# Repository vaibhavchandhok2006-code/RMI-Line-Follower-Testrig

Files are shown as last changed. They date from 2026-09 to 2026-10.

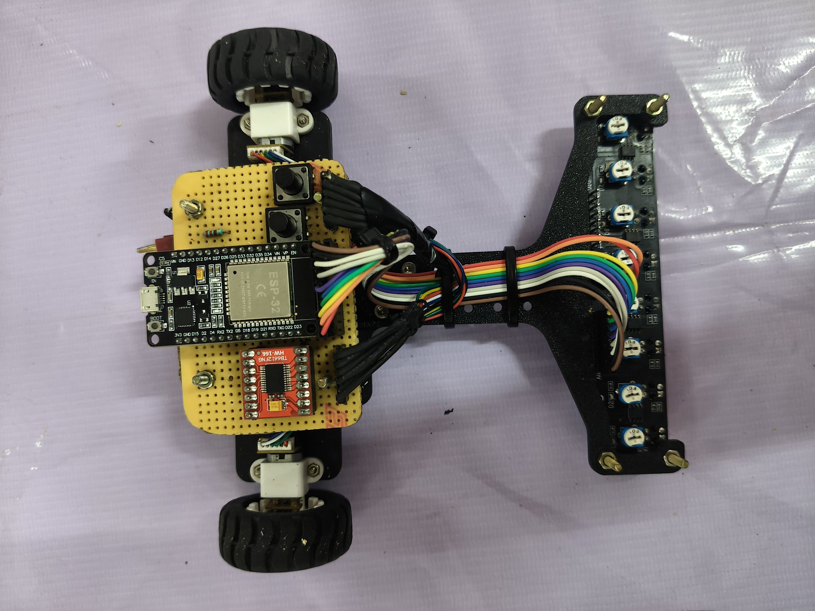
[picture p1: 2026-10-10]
media/photos/05_front_view_sensor_array.jpg

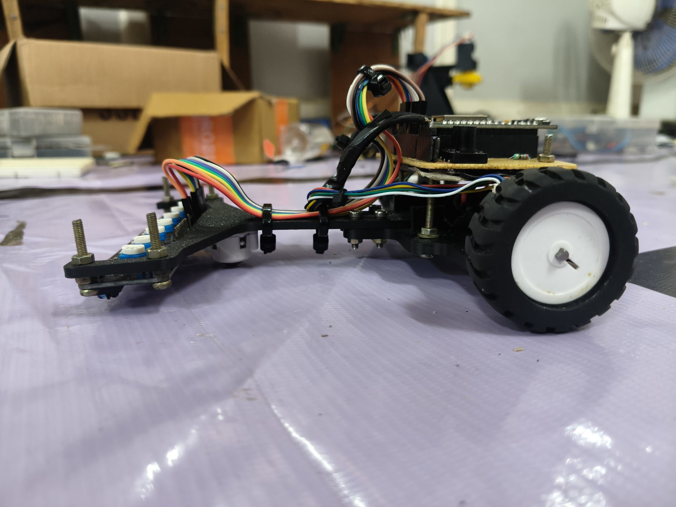
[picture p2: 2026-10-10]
media/photos/04_underside_sensor_array.jpg

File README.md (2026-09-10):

# Line Follower — RMI TestRig Project

## Overview
Differential-drive line-following robot built as a part of RMI Testrig. Follows a 38mm black line through a hostile track (sharp corners, junctions), runs an exploration round to build a track map, then executes an optimized second run using path-planning on the discovered graph.

Design review stage — CAD assembly and circuit design complete, firmware development starting next.

## Repo Structure
- `/cad` — SolidWorks assembly + exported STL files, chassis, motor mounts, sensor mount
- `/docs` — circuit diagram, BOM
- `/firmware` — ESP-IDF firmware (in progress)
- `BUILDLOG - Mentions the project journey
- `README` - Mentions repo structure , project description, required summaries

## Hardware Summary
- ESP32 (compute + control)
- 2× N20 motors with encoders (drive + odometry)
- RLS-08 IR reflectance sensor array (line sensing)
- TB6612FNG motor driver
- 2S LiPo battery, 7.4V nominal, LM2596 buck converter for 5V rail
- Full BOM: see `/docs/bom.md`

## How to Build / Run
Firmware setup instructions will be added once ESP-IDF development begins. CAD files can be opened directly in SolidWorks or viewed via the exported STL file.

## Team
Vaibhav Chandhok, 2nd year Mechanical, RMI Robotics and Machine Intelligence Club , NIT Trichy

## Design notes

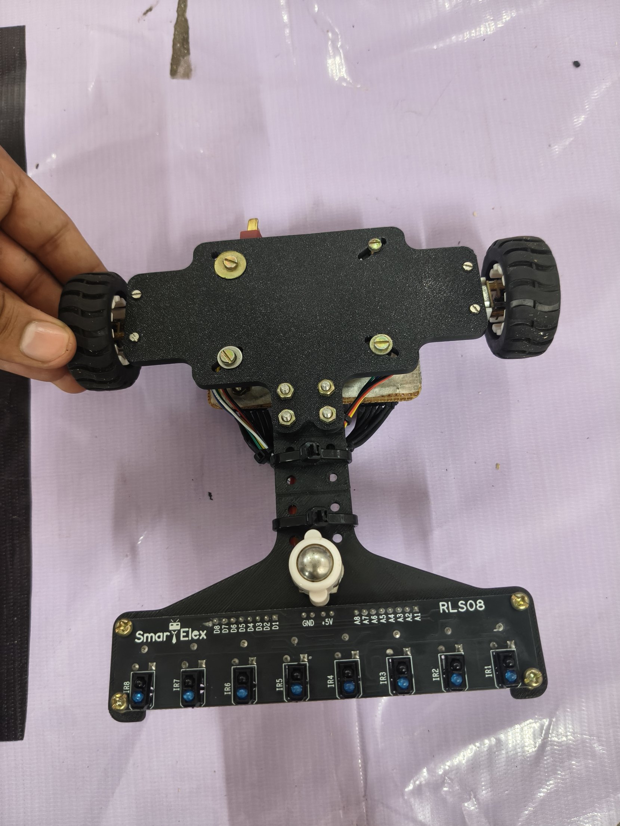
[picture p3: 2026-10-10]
media/photos/06_side_view.jpg

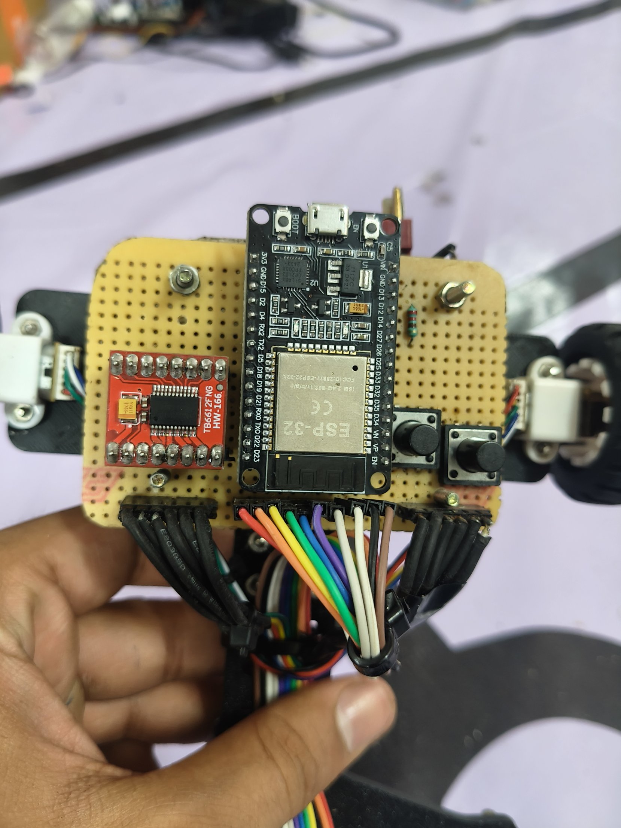
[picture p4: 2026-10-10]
media/photos/03_controller_board_closeup.jpg

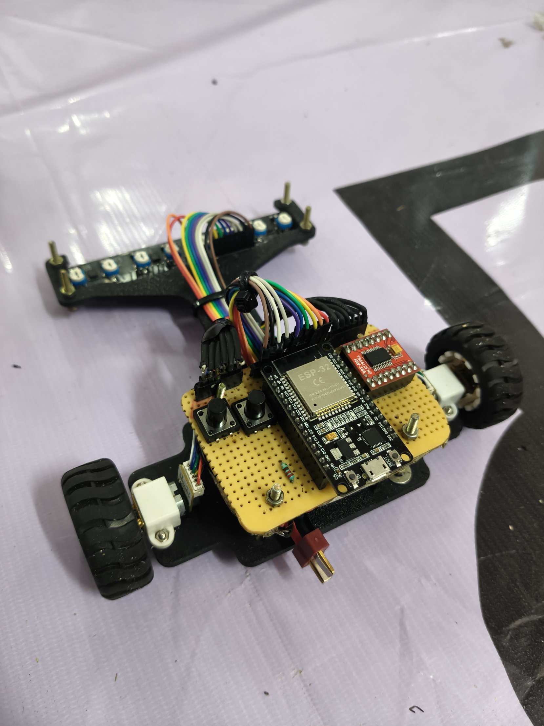
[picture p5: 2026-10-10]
media/photos/01_top_view.jpg

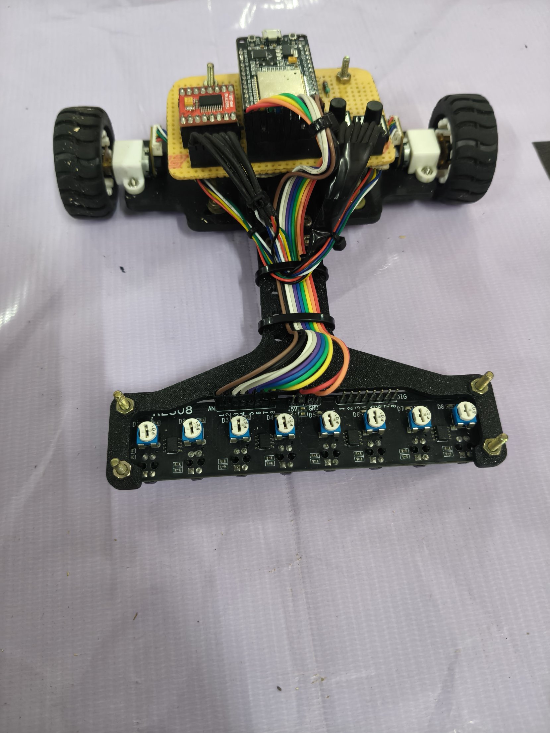
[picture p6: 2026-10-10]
media/photos/02_angled_view.jpg

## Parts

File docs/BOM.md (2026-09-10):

# Bill of Materials

## Electronics — Compute, Sensing, Actuation

| S No. | Component | Quantity | Available in Inventory? |
|---|---|---|---|
| 1 | ESP32 | 1 | Yes |
| 2 | N20 motors with encoders | 2 | Yes |
| 3 | N20 wheels | 2 | Yes |
| — | Caster wheel (compatible with N20 motor height) | 1 | Yes |
| 4 | N20 motor mounts | 2 | Yes |
| 5 | RLS-08 (8-channel IR reflectance sensor array) | 1 | Yes |
| 6 | Motor driver (TB6612FNG) | 1 | Added from personal stock |
| 7 | Battery — LiPo, 7.4V, 850mAh | 1 | Yes |
| 8 | Buck Converter (LM2596, 5V rail) | 1 | Yes |

## Electrical — Wiring, Power, Protection

| S No. | Component | Quantity | Available in Inventory? |
|---|---|---|---|
| 9 | Perfboard, 90×60mm | 1 | Added from personal stock |
| 10 | Male/female header pins | ~20-30 | Yes |
| 11 | JST or XT connector (battery) | 1 | Yes |
| 12 | Jumper wires | ~15-20 | Yes |
| 13 | Voltage divider resistors | Small quantity | Yes |
| 14 | Status LEDs | 2-3 | Yes |
| 15 | Capacitors (voltage smoothing) | As required | Yes |
| 16 | Switches — power on/off, calibration trigger, run trigger | 3 total | Yes |

## Mechanical — Fasteners, Inserts, Structure

| S No. | Component | Quantity | Available in Inventory? |
|---|---|---|---|
| 17 | PLA filament | As needed | Yes |
| 18 | Brass heat-set inserts (PCB mount, motor mount — matched to available bolts in SAC) | 8-10 | Yes |
| 19 | M3 bolts | 10-12 | Yes |
| 20 | Printed or metal standoffs | 4 | Yes |
| 21 | Zip ties, heat-shrink tubing, solder, and other basic build tools | As needed | Yes |

---

**Items sourced outside RMI inventory:** TB6612FNG motor driver and the 90×60mm perfboard were added from personal stock — flagged explicitly per the review's requirement to call out anything not from club inventory.

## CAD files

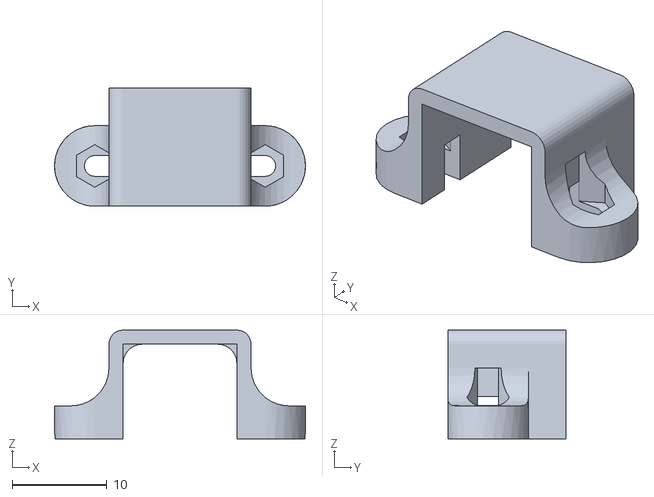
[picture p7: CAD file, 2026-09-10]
cad/parts/N20 motor mount.stl
26.5 x 12.5 x 11.5

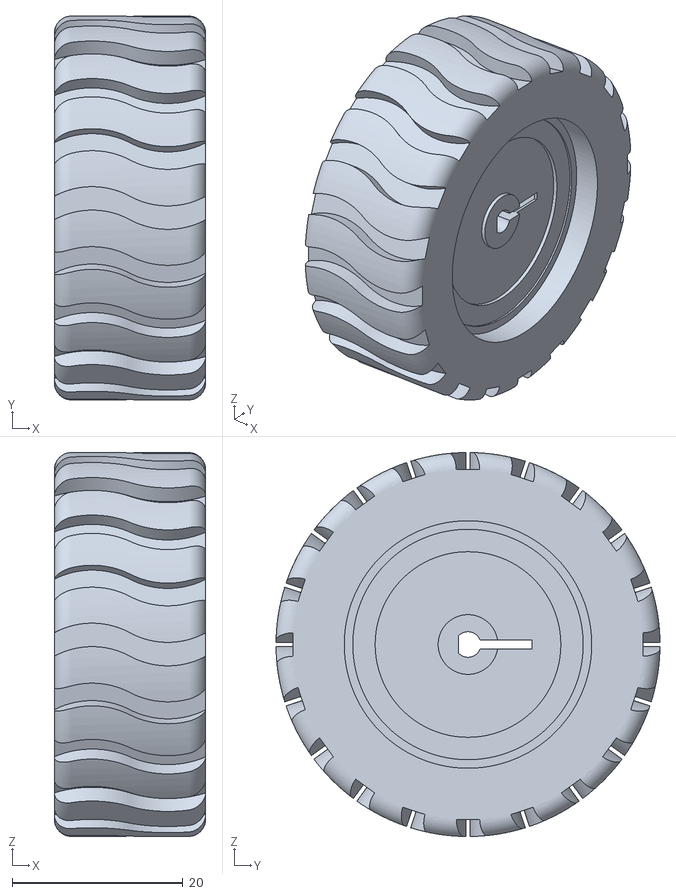
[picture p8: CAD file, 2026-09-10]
cad/parts/N20 Wheel D43 mm.stl
17.8 x 45.0 x 45.0

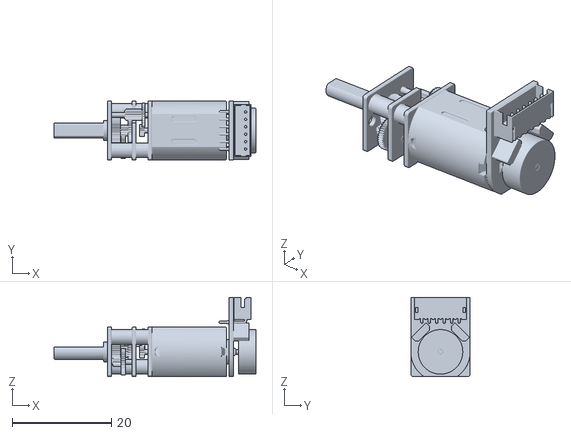
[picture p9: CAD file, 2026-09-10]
cad/parts/n20 motor stl.stl
40.8 x 12.0 x 16.0

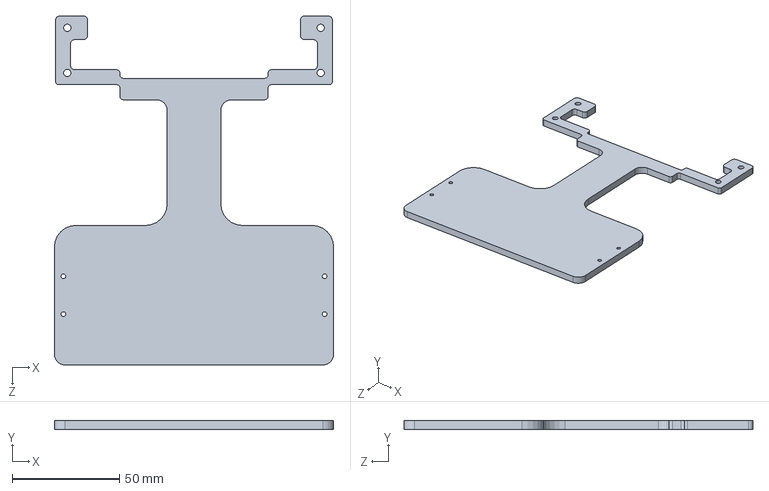
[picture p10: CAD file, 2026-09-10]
cad/parts/Line follower Chasis.SLDPRT
130.0 x 4.00 x 162.5 mm

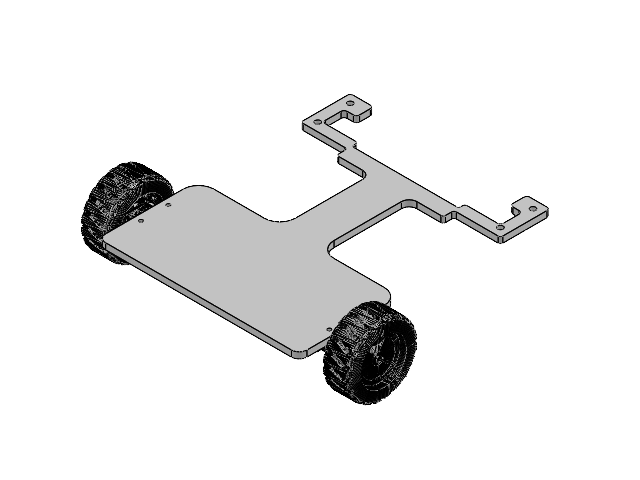
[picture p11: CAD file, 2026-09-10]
cad/parts/Assembly file.SLDASM
Line follower
m20 motor mount sld x 2
n20 motor sldmain x 2
N20 Wheel D43 mm sld x 2

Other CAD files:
cad/parts/n20 motor sldmain.SLDPRT
cad/parts/N20 Wheel D43 mm sld.SLDPRT
cad/parts/m20 motor mount sld.SLDPRT

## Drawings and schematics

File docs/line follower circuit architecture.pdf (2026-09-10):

# Line follower circuit architecture

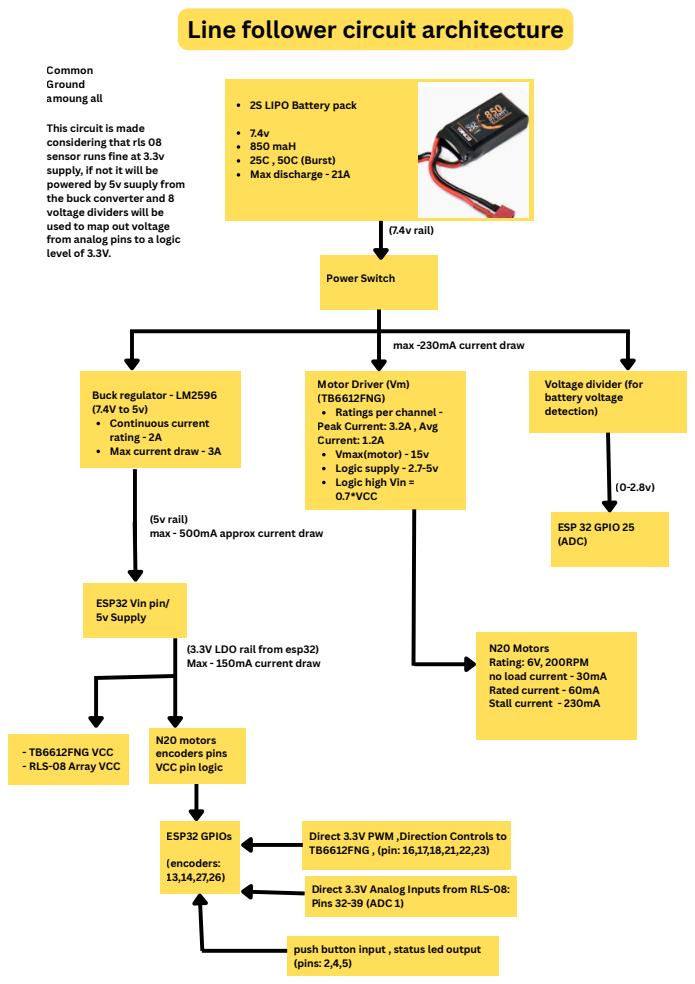
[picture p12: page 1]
7.4v 850 maH 25C , 50C (Burst) Max discharge - 21A; ESP 32 GPIO 25 (ADC); (0-2.8v) ESP32 Vin pin/; 5v Supply; (7.4v rail) Common Ground amoung all; ESP32 GPIOs; (encoders: 13,14,27,26)

2S LIPO Battery pack

This circuit is made
considering that rls 08
sensor runs fine at 3.3v
supply, if not it will be
powered by 5v suuply from
the buck converter and 8
voltage dividers will be
used to map out voltage
from analog pins to a logic
level of 3.3V.

Power Switch Buck regulator - LM2596

max -230mA current draw

Motor Driver (Vm)
(TB6612FNG)
Ratings per channel -
Peak Current: 3.2A , Avg
Current: 1.2A
Vmax(motor) - 15v
Logic supply - 2.7-5v
Logic high Vin =
0.7*VCC

Voltage divider (for
battery voltage
detection)

Continuous current
rating - 2A
Max current draw - 3A

(5v rail)
max - 500mA approx current draw

(3.3V LDO rail from esp32)
Max - 150mA current draw

N20 Motors
Rating: 6V, 200RPM
no load current - 30mA
Rated current - 60mA
Stall current - 230mA

N20 motors
encoders pins
VCC pin logic

- TB6612FNG VCC
- RLS-08 Array VCC

Direct 3.3V PWM ,Direction Controls to
TB6612FNG , (pin: 16,17,18,21,22,23)

Direct 3.3V Analog Inputs from RLS-08:
Pins 32-39 (ADC 1)

push button input , status led output
(pins: 2,4,5)

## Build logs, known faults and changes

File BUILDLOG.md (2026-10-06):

# Build Log

Progressive log of design decisions, what was tried, what changed, and why. 
---

### Aug 7 — Project start
- Allotted the Line Follower project, built a personal roadmap , timeline.
- Started learning Github.
- Set up this GitHub repo.

### Aug ~10-13 — Kinematics
- Learnt about differential  drive kinematics.
- Worked through how sensor mounting offset from the wheel axis affects control

### Aug 13 — Chassis and sensor design constraints research 
- Did a literature survey , used AI tools find the most relevant research papers , links , videos for the project knowledge
- Drafted design requirements sheet: 38mm line, sensor array width, 5-8 sensors, 10-19mm spacing, 5-8mm mount height, front-mounted array ahead of wheel axle.
- Made a rough component list
- Through the learnings from the literature survey defined design requirements 

### Aug 13-15 — Sensor hardware verification
- Checked actual RLS-05/RLS-08 datasheets against assumed design numbers. Found the initially planned mounting height (8-12mm) was too high for the real sensors' recommended sensing distance (RLS-08: ~6mm, RLS-05: ~3mm optimal). Corrected target to 5-6mm with adjustable mount.
- Computed array width and critical entry angle for available options:
  - RLS-08 full 8ch: 105mm width 
- Decision: proceeded with full RLS-08 (8ch) after confirming inventory availability — to be validated against actual measured track .

### Aug 15-20 — Circuit architecture, CAD Design and component finalization
- Finalized BOM: confirmed availability of ESP32, N20 motors w/ encoders, caster wheel, motor mounts, RLS-08, TB6612FNG,Battery , Buck converter and mechanical hardware in RMI inventory.
- Designed power architecture: 2S LiPo (7.4V nominal) → power switch → splits to (a) TB6612FNG VM pin directly, (b) LM2596 buck converter → 5V rail → ESP32 VIN + N20 encoder VCC + level shifter HV side.
- Caught a real issue: N20 encoder outputs run at 5V logic, which would be unsafe wired directly into ESP32's 3.3V-only GPIOs. Added a 4-channel logic level shifter to bring encoder signals down to 3.3V.
- Assigned all 8 RLS-08 analog channels to ESP32 ADC1 pins (GPIO32-39) specifically because ADC2 becomes unreliable once Wi-Fi is active — needed for the telemetry stretch objective.
- Routed battery voltage divider to GPIO25 (ADC2) as a deliberate exception, since battery monitoring doesn't need real-time precision the way line sensing does.
- Sized battery voltage divider (10kΩ / 5.6kΩ) so that worst-case 8.4V (full charge) maps to ~3.02V at the ESP32 ADC pin, safely under the 3.3V limit.
- Computed peak current budget (~3A instantaneous: 2× motor stall + Wi-Fi-active ESP32 + sensor array) to size the battery/driver requirements.
- Built the first draft of the Chasis

### Aug 20 -22 — CAD assembly
- Donwloaded the n20 motor , mounts , wheel cad models from grabcad
- Built first-pass chassis assembly in SolidWorks: N20 motors, motor mounts, wheels assembled onto chassis baseplate.

### Aug 23 — Design review

### Aug 26 — Circuit reiteration: component spec audit

Design review on the 23rd landed mid-CT, so a lot of it was deadline-chasing rather than actually thinking things through. Today's the real reiteration pass — went back to first-party specs for every major component instead of the assumed numbers from before.

- **RLS-08 IR array**: 100–150mA draw, rated 5V, gives 0–5V analog out (per Robu.in). Also runs at 3.3V, but only if the LED current-limiting resistor stage (two-stage arrangement on-board) is shorted/bypassed — needs on-board soldering rework.(to be confirmed)
  - If the bypass works: 3.3V is sufficient, no voltage divider needed on the 8 analog lines.
  - If not: fall back to 5V off the buck converter + 8× voltage dividers to bring the ADC lines to 3.3V logic.
  - Not decided yet — will try the 3.3V supply.
- **N20 motor**: 6V rated, 200RPM. No-load current 30mA, rated 60mA, stall 230mA.
- **N20 encoder**: red/blue = GND + motor power, black = encoder VCC (3.3–5V logic), yellow/green = signal feedback (logic-high tracks whatever VCC is supplied). Going with 3.3V logic to match ESP32 GPIOs directly.
- **TB6612FNG driver**: 1.2A continuous / 3.2A peak per channel, Vmotor max 15V, logic supply 2.7–5.5V. Logic-high threshold is 0.7×VCC — this is the actual reason 3.3V logic was chosen over 5V: at 3.3V VCC the threshold sits low enough for ESP32's native 3.3V GPIO high to drive it cleanly. At 5V VCC, the threshold would sit above what a 3.3V GPIO can output.
- **Battery**: 7.4V 2S LiPo, 850mAh, 25C continuous / 50C burst, ~21A max discharge.
- **ESP32**: onboard LDO accepts 5–12V in, fed from the buck-converted 5V rail → 3.3V LDO out. Max output 250mA , per GPIO - 20mA recommended, Wi-Fi/BT TX peak current 240–500mA — factored into the current budget.
- **Buck converter (LM2596)**: 2A continuous, 3A max — heatsink required above ~2A.

**Open question:** whether to feed the raw 7.4V LiPo rail straight into ESP32 Vin. Technically within the 5–12V input range but still need to confirm , some online source suggested that ideally 5-7V should be fed into esp32 LDO.

Updated circuit architecture diagram reflects all of the above: 7.4V rail → power switch → splits three ways (buck → 5V rail, direct to motor driver Vm, divider → battery-voltage ADC). Pin assignments locked: encoders on GPIO13/14/27/26, motor driver PWM+direction on 16/17/18/21/22/23, RLS-08 analog on GPIO32-39 (ADC1), push button + status LED on 2/4/5.

Next: once the RLS-08 power path is settled , will move to CAD assemble re - ideation .

### Aug 27–29 — Chassis v2: split design, adjustable sensor arm

(Didn't log day-by-day through this stretch — heads-down on CAD. Catching up in one entry covering the full 3-day iteration.)

The previous chassis was rushed to hit the design review deadline and wasn't actually good. This is the real redesign.

**Split into two parts** instead of one solid baseplate:
1. **Back chassis plate** — motor mounts + PCB area + battery mount
2. **Adjustable IR sensor arm** — separate piece, bolts on

**Back chassis plate**
- Previous version was one full rectangular block, which carried dead weight on either side of the motors for no reason. New version thins those sections down to just what the motor mounts need, cutting that mass out.
- PCB footprint minimized to 80mm × 60mm to keep mass down; PCB sits on standoffs ~1.5–2cm above the plate.
- 4mm thick, printed at 60% infill.
- The PCB Mounting fall are made as slots rather than fixed holes if a smaller PCB is possible to make it can mounted and hence the mounting holes are adjustable.

**Adjustable IR sensor arm:**
- Look-ahead distance adjustable from 8cm to 20cm, with 1cm-spaced grooves as cut guides. Once track calibration shows the ideal look-ahead distance, the arm gets trimmed to length and bolted to the chassis plate through two front mounting holes.
- Originally planned to mount this *below* the back plate, but that removed the ground clearance for the sensor head and removed any adjustability — moved it above instead.
- 3mm thick (kept minimal since it's not load-bearing), printed at 70–80% infill to compensate for the reduced thickness.
- Caster wheel sits directly below the arm's front section, with a 2mm gap between the arm's underside and the caster when mounted. No threaded mount for the caster — will be secured with double-sided tape instead of screws.

**Test prints completed:** caster wheel mounting hole, bolt diameter tolerances, IR sensor array mount. Final full-chassis prints still pending.

**Custom CAD parts modeled from scratch** (no usable models existed online): LiPo battery, caster wheel, IR sensor array — built to complete the full assembly for fit-checking.

**Full assembly**


**Chasis Main Back Plate**



**Adjustable IR Sensor array part with Castor wheel and cutting grooves**


**Chassis assembly complete, all parts 3D printed**
- All chassis parts printed in PLA 3D Printer and assembled: baseplate, N20 motor mounts, wheels, caster mount.
- Final assembly photo:
IMG_20260829_163451 jpg

- Mechanical build phase complete. Moving into electronics wiring and ESP-IDF firmware development next.

### Sep 1 — ESP-IDF setup, first GPIO program
- ESP-IDF installed and toolchain working (separate learning curve from Arduino IDE — different build system, no hand-holding on peripheral config).
- Wrote first "Hello World" program to confirm the flash/build/monitor workflow.
- Wrote first LED blink program using raw GPIO driver calls (gpio_reset_pin, gpio_set_level, vTaskDelay) instead of Arduino's digitalWrite/delay abstractions.
- Decision: spending few days on ESP-IDF fundamentals before touching sensor/motor code, given how different the peripheral driver model is from Arduino. Following an online ESP-IDF tutorial series to build this foundation properly rather than rushing into the project code cold.
- Learned to configure and control multiple output pins .
- Learned digital input handling — reading a push button through ESP-IDF's GPIO input configuration (pull-up/pull-down config, gpio_get_level()).

### Sep 3-4 — PWM/LEDC control, first real ESP-IDF build issue
- Learned to control LED brightness via PWM using ESP-IDF's LEDC peripheral driver.
- Hit the first real build failure of the project: `fatal error: driver/ledc.h: No such file or directory`.

### Sep 9 — Sensor hardware setback, motor control confirmed working
- Discovered a hardware fault on the RLS-08: connecting 5V and GND caused the ESP32/Arduino power supply itself to browning out/switch off — strongly indicates a short on the sensor board, not a wiring or code issue on my end.
- As a temporary workaround, tested a spare 5-channel digital IR sensor module. Digital reads worked correctly in firmware, but the board itself is unusable for this project: its onboard threshold-setting potentiometer was never soldered at the factory, so there's no way to calibrate detection thresholds on it.
- Decision: waiting for the RLS-08 to be audited/replaced rather than building around the substitute digital board. The project spec explicitly requires a continuous weighted position estimate, which a digital (on/off per channel) sensor fundamentally cannot provide regardless of calibration — so this isn't a workaround worth forcing, it's the wrong sensor type for the requirement.
- Meanwhile, progressed on a parallel subsystem: single motor (Motor A) digital control via TB6612FNG fully working — forward/stop/reverse cycle confirmed on real hardware, STBY/AIN1/AIN2/PWMA wiring and control logic verified correct.
- Next: motor B, then PWM speed control layered on top of the working digital control, while sensor hardware issue is resolved in parallel.

## 10th September 2026 - Motor Control Hardware Drivers, PWM Integration & Firmware Repo Setup

### Summary
Successfully upgraded the dual DC motor driver firmware on ESP32 to support PWM speed control using ESP-IDF's LEDC peripheral. Structured the initialization routines into clean setup functions and integrated the local project folder into the main GitHub repository structure.

### Hardware & Pins Configured
* **Motor A (Left Drive):** `PWMA` (GPIO 16), `AIN1` (GPIO 17), `AIN2` (GPIO 18)
* **Motor B (Right Drive):** `PWMB` (GPIO 19), `BIN1` (GPIO 21), `BIN2` (GPIO 22)
* **Driver Control:** `STBY` (GPIO 23)

### Firmware Implementation Details
1. **GPIO & Direction Control:** Configured directional H-Bridge outputs (`AIN1/2`, `BIN1/2`) and driver enable (`STBY`).
2. **LEDC Hardware PWM Integration:** 
   * Configured `LEDC_TIMER_0` in `LEDC_LOW_SPEED_MODE` running at **5 kHz** to eliminate audible motor whine.
   * Configured **10-bit resolution** (duty cycle values from `0` to `1023`).
   * Linked `LEDC_CHANNEL_0` to Motor A (`PWMA`) and `LEDC_CHANNEL_1` to Motor B (`PWMB`).
3. **Control Routines:**
   * Modularized setup into `gpio_init()`, `pwm_init()`, and a master `motor_system_init()` sequence to prevent floating pin motor twitching on startup.
   * Created safe dynamic motor functions (`set_motor_a_speed`, `set_motor_b_speed`) with speed range clamping protection.

### Challenges & Resolutions
* **Git Remote Conflict (`non-fast-forward`):** Encountered push rejections due to diverged history between remote updates (`BUILDLOG.md`) and local files. Resolved using `git pull origin main --allow-unrelated-histories`.
* **File Structure Merge Conflict:** Conflict arose over `firmware/.gitignore` present in both local and remote branches. Aborted rebase, resolved conflicts, and staged manually using `git add .` and a merge commit.
* **Line Ending Conversion (CRLF/LF):** Handled cross-platform line ending normalization warnings during Git staging on Windows.
* **IntelliSense Include Path Warnings:** Identified red squiggly lines under `#include <driver/gpio.h>` as VS Code header resolution warnings caused by file directory restructuring; verified code compilation independently.

## not yet resolved
- RLS-08 power path: 3.3V direct (needs resistor-stage bypass mod) vs 5V + 8× voltage dividers — pending 3.3V feasibility test
- ESP32 Vin: raw 7.4V LiPo direct vs regulated 5V rail — undecided (raw only possible if the rls sensor runs at 3.3V)

### Sep 17 — Motor driver integration confirmed, borrowed RLS-08 for sensor code testing, baseline subtraction issue diagnosed

**Motor control — done, encoders not yet integrated**
- Motor driver (TB6612FNG) integration confirmed working on real hardware: forward, reverse, and stop all verified with both motors under LEDC PWM control.
- Encoders not wired in yet — motor motion currently open-loop, no speed/position feedback. Consistent with the roadmap: encoders are a deferred stretch item (odometry), not required for core.

**Sensor testing — using a borrowed RLS-08, own unit still not delivered**
- My own RLS-08 hasn't arrived yet. Borrowed another RMI member's RLS-08 unit specifically to test and develop the sensor-reading code against real hardware in the meantime, rather than staying blocked.
- Ran the 8-channel sensor test code (6ch on ADC1, 2ch on ADC2) against the borrowed array and logged real readings across a range of hand-swept positions over the line.

**Diagnosed: white-baseline subtraction issue**
- Logged data showed the line (black) consistently read higher than background (white), confirming correct polarity — no inversion needed in the weighted-position formula.
- However, all sensors carried a substantial baseline offset (~80-100 raw counts) even on plain white background. Since the weighted-average formula divides by the sum of all raw readings, this baseline was diluting the effective signal — reworking one logged example (strong left-side line detection) showed the computed position was roughly 3x weaker than physically expected once the baseline was accounted for by hand.
- Root cause: sensor readings were being used raw/uncalibrated, with no per-sensor min/max subtraction or normalization. This is exactly the calibration requirement the spec mandates, now confirmed empirically rather than just theoretically.
- Also observed: sensor-to-sensor baseline varies by 10-20 raw counts even on identical white background — consistent with expected manufacturing/mounting variation discussed earlier, reinforces need for *per-sensor* calibration rather than a single shared threshold.
- Observed contrast (white vs black) is currently small in absolute terms, and improves when sensor height is reduced. Decision: check for an onboard gain trimmer before lowering mount height further, since height reduction trades contrast for ground clearance against the paper track's bends/folds.

### Sep 18 — Rebuilt on new breadboard, borrowed sensor calibration tested, key diagnostic on position range

**Hardware changes**
- Rebuilt the full circuit on a different breadboard (previous one belonged to another member). Re-wired motors, driver, and the borrowed I2C/analog sensor array from scratch.
- Sensor array VIN wired to 5-6V, analog outputs to ADC-capable GPIOs as before.

**Sensor height tuning**
- At ~1-2mm mounting height, readings were extremely sensitive: a slight fold in the flex track caused raw values to jump from ~200 to 2000-3000, making the signal unusable.
- Taped and flattened the flex track to the floor to remove fold-induced noise at the source, rather than relying on software to compensate.
- Settled on ~5-6mm mounting height as a deliberate compromise: raw contrast is weaker than at 1-2mm, but the reading is far more stable against small surface imperfections. Chose robustness over maximum contrast.
- Noted raw ADC values are compressed to roughly 50-200 out of the 0-4095 range even at the higher contrast extreme — this sensor's native contrast is low regardless of height, consistent with it being a borrowed unit rather than the intended RLS-08.

**Calibration routine refined**
- Settled on a physical sweep method: both wheels kept in contact with the ground, sliding the whole chassis left-to-right slowly by hand. Deliberately avoided a rotational/arc sweep after testing it — rotating caused the sensor array to lift slightly off the surface, corrupting the calibration exactly as predicted.
- Ran the button-toggled calibration code (min/max per sensor, mapped to 0-1000) successfully. Logged full calibration runs.

**Diagnosed: compressed position range (~±12 instead of the full ±52.5 weight range)**
- Analyzed logged data: even at maximum observed swing, multiple adjacent sensors carry substantial signal simultaneously rather than one sensor dominating cleanly. This compresses the weighted-average centroid well below the geometric extreme.
- Root cause identified as the sensor's weak native contrast (confirmed by the 50-200 raw range) causing a broad, overlapping reflectance response across multiple channels, rather than a sharp per-sensor on/off falloff -- not a bug in the position-calculation math.
- Confirmed this is acceptable for control purposes regardless: the position value is monotonic and repeatable, particularly well-behaved near center ("once center reads near zero, it works almost everywhere"), which is what PID actually needs -- full range utilization is not a requirement.
  

WhatsApp Image 2026-09-19 at 2 22 29 PM

### Sep 21 — Exploration research, Algorithm 1 vs 2 overview & track loop conflict

**Research paper review & algorithm overview**
- Reviewed a senior's research paper on line-maze solving to understand potential exploration strategies ahead of the Sept 30 core deadline.
- **Algorithm 1 (Fixed Preference / Stack Backtracking):**
  - Uses no wheel encoders or $(x, y)$ coordinate tracking; relies purely on binary junction triggers and dead-end backtracking.
  - *Limitation:* Built for simple tree-structured mazes. Assumes every bad path ends in a dead end that forces a backtrack.
- **Algorithm 2 (Coordinate Mapping & Dijkstra):**
  - Requires wheel encoders, compass heading, and trigonometric path-length correction to cross-reference coordinates and detect loop closures.
  - *Note:* Encoders remain un-wired on the current chassis, making Algorithm 2 a heavy addition to implement within the days left.

**Track overview & potential conflict**
- Looked at the official track layout: features a connected grid network with multi-intersecting closed loops at the bottom, alongside special geometry (diamond cutouts, circular loops).
- *Key Takeaway:* Standard Algorithm 1 (and pure LSRB) will fail on this track layout. Because intersecting loops feed back into previously visited paths without dead-ending, fixed-preference rules will cause the robot to get trapped in infinite orbits.

**Revised algorithm plan & progress status**
- Need to properly read through the rest of the paper and examine a lightweight loop-handling exploration algorithm that handles closed loops without requiring hardware encoders.
- Exploration phase remains aligned with the Sept 25–28 roadmap window.
- Hardware status: Encoders remain dropped as a stretch goal; perfboard/power supply fabrication deferred as low-risk mechanical work to protect algorithm development time.

### Sep 22–30 — PID, Junction Handling & Final Hardware Integration

- Integrated the calibrated RLS-08 readings with continuous weighted line-position estimation and implemented closed-loop PID line following on the physical track.
- Tuned the controller experimentally on the actual track. After testing different speeds and gains, the stable baseline converged to:
  - `BASE_SPEED = 1000 / 1023`
  - `Kp = 55`, `Ki = 0`, `Kd = 1.5`
  - Filtered derivative with `alpha = 0.2`
- Developed binary sensor-pattern based junction detection using experimentally observed patterns from the track.
- Added a multi-sample confirmation window to reduce false detections and distinguish an L-junction from a left-branch T-junction by checking for continued straight-line detection in later samples.
- Implemented a dedicated junction-turning state. PID is temporarily disabled, the robot performs a fixed-duration differential spin, and then PID resumes. The left-turn duration was initially set to `350 ms`.
- Corrected the physical turn direction in software after discovering that the final motor wiring orientation was opposite to the assumed polarity.
- Designed and built a **standalone permanent perfboard**, soldering the complete electronics onto a single board instead of relying on the temporary breadboard setup. The ESP32, motor driver, power connections, sensor connections and supporting circuitry were integrated into the permanent assembly.
- Added persistent sensor calibration using ESP32 NVS, allowing `sensor_min[]` and `sensor_max[]` to be saved to flash and automatically restored after power cycles. Recalibration overwrites the stored values.
- Continued physical testing and debugging of the integrated robot, particularly around junction detection, turning behaviour and electrical connection stability.
- By the end of this phase, the rig had a working calibrated PID line-following system with the first layer of junction detection and physical junction execution.
- Exploration, path representation and route optimization remain the next major layer to be implemented.

### Oct 1 - Oct 6 — Maze-Solving Algorithm Exploration

- Explored the next stage of the project: maze exploration, node identification, branch tracking and shortest-path generation.
- Initially considered a DFS + graph approach, but identified a key issue: without a reliable way to recognize a previously visited node, the robot cannot know whether a branch is actually unexplored.
- Considered a simple path/LSRB-based approach:
  - Simple and does not require mapping.
  - Problem: not reliable for complex mazes with loops and multiple routes.
- Explored a graph-based approach:
  - Allows explicit tracking of nodes, branches and explored paths.
  - Problem: requires a reliable method to identify when the robot has returned to an existing node.
- Studied a coordinate-based maze-mapping approach using wheel encoders:
  - Junctions are assigned coordinates and matched against previously visited coordinates within a tolerance.
  - Branches can then be tracked as explored/unexplored and the complete maze can be represented as a graph.
  - Dijkstra can subsequently be used to obtain the shortest path.
  - Problem: requires reliable encoder integration, heading estimation and coordinate accuracy.
- Also considered the additional complexity of correcting encoder distance for the robot's non-linear/zig-zag motion.
- **Current status:** Final maze-solving architecture is not yet locked. We are continuing to evaluate the trade-offs between a simpler exploration approach and a coordinate/encoder-based graph-mapping approach before implementation.

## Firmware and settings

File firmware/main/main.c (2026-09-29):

/*
 * ESP32 Line Follower Robot
 * Features:
 * - 8 Sensor Line Position Detection
 * - Single-Button Control State Machine (GPIO 4)
 * - Closed-Loop PID Control
 * - Unconditional Straight Probe Window with Flexible Straight-Line Classifier
 */

#include <stdio.h>
#include <stdbool.h>
#include "freertos/FreeRTOS.h"
#include "freertos/task.h"
#include "esp_adc/adc_oneshot.h"
#include "esp_log.h"
#include "esp_timer.h"
#include "driver/gpio.h"
#include "driver/ledc.h"

static const char *TAG = "LINE_FOLLOWER";

/* =========================================================================
 * 1. HARDWARE PINS & SENSOR CONFIGURATION
 * ========================================================================= */
#define NUM_SENSORS        8
#define INVERT_LINE_LOGIC  false

// Single Control Button (GPIO 4)
#define BTN_SINGLE_GPIO    GPIO_NUM_4
#define DEBOUNCE_TIME_MS   300

// Status LEDs
#define LED_CALIB_GPIO     GPIO_NUM_2
#define LED_RUN_GPIO       GPIO_NUM_0

// ADC Channels assigned to sensors (6 on ADC1, 2 on ADC2)
static const adc_channel_t adc1_channels[6] = {
    ADC_CHANNEL_0, ADC_CHANNEL_3, ADC_CHANNEL_6,
    ADC_CHANNEL_7, ADC_CHANNEL_4, ADC_CHANNEL_5
};
static const adc_channel_t adc2_channels[2] = {
    ADC_CHANNEL_8, ADC_CHANNEL_9
};

// Distance of each sensor from the center line
static const float sensor_weight[NUM_SENSORS] = {
    -52.5f, -37.5f, -22.5f, -7.5f, 7.5f, 22.5f, 37.5f, 52.5f
};

static adc_oneshot_unit_handle_t adc1_handle;
static adc_oneshot_unit_handle_t adc2_handle;

static int sensor_min[NUM_SENSORS];
static int sensor_max[NUM_SENSORS];
static bool is_calibrated = false;

/* =========================================================================
 * 2. ROBOT STATE MACHINE
 * ========================================================================= */
typedef enum {
    ROBOT_STATE_IDLE = 0,
    ROBOT_STATE_CALIBRATING,
    ROBOT_STATE_RUNNING
} robot_state_t;

static volatile robot_state_t robot_state = ROBOT_STATE_IDLE;
static volatile bool btn_pressed = false;

/* =========================================================================
 * 3. MOTOR CONTROL & PWM CONFIGURATION
 * ========================================================================= */
#define AIN1      GPIO_NUM_17
#define AIN2      GPIO_NUM_18
#define BIN1      GPIO_NUM_13
#define BIN2      GPIO_NUM_22
#define STBY      GPIO_NUM_23
#define PWMA_PIN  GPIO_NUM_16
#define PWMB_PIN  GPIO_NUM_19

#define LEDC_MODE       LEDC_LOW_SPEED_MODE
#define LEDC_TIMER      LEDC_TIMER_0
#define LEDC_DUTY_RES   LEDC_TIMER_10_BIT
#define LEDC_FREQUENCY  5000
#define CHANNEL_A       LEDC_CHANNEL_0
#define CHANNEL_B       LEDC_CHANNEL_1

#define MAX_DUTY        1023
#define BASE_SPEED      1000

/* =========================================================================
 * 4. JUNCTION PROBE & CLASSIFICATION CONFIGURATION
 * ========================================================================= */
#define JUNCTION_STRAIGHT_SPEED      500    // PWM speed during probe
#define JUNCTION_STRAIGHT_DRIVE_MS   250    // Time (ms) to drive straight past junction stem
#define JUNCTION_COOLDOWN_MS         1000   // Cooldown between triggers

#define CENTER_REGION_MASK           0x3C   // Middle 4 sensors: S5, S4, S3, S2 (0b00111100)

static bool junction_probing_active = false;
static int64_t junction_probe_start_us = 0;
static int64_t last_junction_time_us = 0;

/*
 * Returns true if current binary pattern matches known Left Junction triggers.
 */
bool is_left_junction_pattern(uint8_t binary)
{
    switch (binary)
    {
        case 0b11111100:
        case 0b11111000:
        case 0b11110000:
        case 0b11111110:
        case 0b11111001:
        case 0b01011000:
            return true;

        default:
            return false;
    }
}

/*
 * Multi-case + Count/Mask hybrid check for Straight Line Presence
 */
bool check_straight_line_exists(uint8_t binary, int count)
{
    // Specific pattern matches for standard/shifting straight lines
    switch (binary)
    {
        case 0b00011000: // Ideal center (S3, S4)
        case 0b00010000: // S4 single
        case 0b00001000: // S3 single
        case 0b00111000: // S3, S4, S5 (3-sensor wide)
        case 0b00011100: // S2, S3, S4 (3-sensor wide)
        case 0b00110000: // S4, S5
        case 0b00001100: // S2, S3
            return true;

        default:
            break;
    }

    // Fallback: Check if ANY of the middle 4 sensors are active with a valid line count
    if ((binary & CENTER_REGION_MASK) != 0 && count >= 1) {
        return true;
    }

    return false;
}

/* =========================================================================
 * 5. PID CONTROLLER STRUCT & STATE
 * ========================================================================= */
#define DERIVATIVE_FILTER_ALPHA 0.2f

typedef struct {
    float kp;
    float ki;
    float kd;
    float integral;
    float prev_error;
    float integral_limit;
    float filtered_derivative;
    bool  first_sample;
} pid_t;

static pid_t line_pid = {
    .kp                  = 55.0f,
    .ki                  = 0.0f,
    .kd                  = 1.5f,
    .integral            = 0.0f,
    .prev_error          = 0.0f,
    .integral_limit      = 50.0f,
    .filtered_derivative  = 0.0f,
    .first_sample        = true
};

/* =========================================================================
 * 6. INTERRUPT SERVICE ROUTINES & DEBOUNCED SINGLE BUTTON
 * ========================================================================= */
static volatile uint64_t last_btn_time_ms = 0;

static void IRAM_ATTR button_isr_handler(void* arg)
{
    uint64_t now_ms = esp_timer_get_time() / 1000;

    if ((now_ms - last_btn_time_ms) > DEBOUNCE_TIME_MS) {
        btn_pressed = true;
        last_btn_time_ms = now_ms;
    }
}

void buttons_init(void)
{
    gpio_config_t io_conf = {
        .pin_bit_mask = (1ULL << BTN_SINGLE_GPIO),
        .mode         = GPIO_MODE_INPUT,
        .pull_up_en   = GPIO_PULLUP_ENABLE,
        .pull_down_en = GPIO_PULLDOWN_DISABLE,
        .intr_type    = GPIO_INTR_NEGEDGE
    };
    gpio_config(&io_conf);

    gpio_install_isr_service(0);
    gpio_isr_handler_add(BTN_SINGLE_GPIO, button_isr_handler, (void*) BTN_SINGLE_GPIO);
}

/* =========================================================================
 * 7. LED STATUS INDICATORS
 * ========================================================================= */
void leds_init(void)
{
    uint64_t mask = (1ULL << LED_CALIB_GPIO) | (1ULL << LED_RUN_GPIO);
    gpio_config_t io_conf = {
        .pin_bit_mask = mask,
        .mode         = GPIO_MODE_OUTPUT,
        .pull_up_en   = GPIO_PULLUP_DISABLE,
        .pull_down_en = GPIO_PULLDOWN_DISABLE,
        .intr_type    = GPIO_INTR_DISABLE
    };
    gpio_config(&io_conf);

    gpio_set_level(LED_CALIB_GPIO, 0);
    gpio_set_level(LED_RUN_GPIO, 0);
}

void update_leds(void)
{
    static uint32_t blink_counter = 0;

    switch (robot_state) {
        case ROBOT_STATE_IDLE:
            gpio_set_level(LED_CALIB_GPIO, is_calibrated ? 1 : 0);
            gpio_set_level(LED_RUN_GPIO, 0);
            break;

        case ROBOT_STATE_CALIBRATING:
            blink_counter++;
            gpio_set_level(LED_CALIB_GPIO, (blink_counter / 12) % 2);
            gpio_set_level(LED_RUN_GPIO, 0);
            break;

        case ROBOT_STATE_RUNNING:
            gpio_set_level(LED_CALIB_GPIO, 1);
            gpio_set_level(LED_RUN_GPIO, 1);
            break;
    }
}

/* =========================================================================
 * 8. SENSOR PROCESSING FUNCTIONS
 * ========================================================================= */
void sensors_init(void)
{
    adc_oneshot_unit_init_cfg_t cfg1 = { .unit_id = ADC_UNIT_1, .clk_src = ADC_RTC_CLK_SRC_DEFAULT };
    ESP_ERROR_CHECK(adc_oneshot_new_unit(&cfg1, &adc1_handle));

    adc_oneshot_unit_init_cfg_t cfg2 = { .unit_id = ADC_UNIT_2, .clk_src = ADC_RTC_CLK_SRC_DEFAULT };
    ESP_ERROR_CHECK(adc_oneshot_new_unit(&cfg2, &adc2_handle));

    adc_oneshot_chan_cfg_t chan_cfg = { .bitwidth = ADC_BITWIDTH_12, .atten = ADC_ATTEN_DB_12 };

    for (int i = 0; i < 6; i++) {
        ESP_ERROR_CHECK(adc_oneshot_config_channel(adc1_handle, adc1_channels[i], &chan_cfg));
    }
    for (int i = 0; i < 2; i++) {
        ESP_ERROR_CHECK(adc_oneshot_config_channel(adc2_handle, adc2_channels[i], &chan_cfg));
    }

    for (int i = 0; i < NUM_SENSORS; i++) {
        sensor_min[i] = 4095;
        sensor_max[i] = 0;
    }

    ESP_LOGI(TAG, "Sensors initialized.");
}

void read_sensors(int *raw)
{
    for (int i = 0; i < 6; i++) {
        ESP_ERROR_CHECK(adc_oneshot_read(adc1_handle, adc1_channels[i], &raw[i]));
    }
    for (int i = 0; i < 2; i++) {
        ESP_ERROR_CHECK(adc_oneshot_read(adc2_handle, adc2_channels[i], &raw[6 + i]));
    }
}

void update_calibration(const int *raw)
{
    for (int i = 0; i < NUM_SENSORS; i++) {
        if (raw[i] < sensor_min[i]) sensor_min[i] = raw[i];
        if (raw[i] > sensor_max[i]) sensor_max[i] = raw[i];
    }
}

void get_calibrated_values(const int *raw, int *calibrated)
{
    for (int i = 0; i < NUM_SENSORS; i++) {
        int range = sensor_max[i] - sensor_min[i];
        if (range <= 0) {
            calibrated[i] = 0;
            continue;
        }

        int val = raw[i];
        if (val < sensor_min[i]) val = sensor_min[i];
        if (val > sensor_max[i]) val = sensor_max[i];

        int mapped = ((val - sensor_min[i]) * 1000) / range;
        calibrated[i] = INVERT_LINE_LOGIC ? (1000 - mapped) : mapped;
    }
}

float get_weighted_position(const int *calibrated)
{
    float numerator = 0.0f;
    float denominator = 0.0f;

    for (int i = 0; i < NUM_SENSORS; i++) {
        numerator += (float)calibrated[i] * sensor_weight[i];
        denominator += (float)calibrated[i];
    }

    if (denominator == 0.0f) return 0.0f;
    return numerator / denominator;
}

uint8_t get_sensors_binary(const int *calibrated)
{
    uint8_t binary = 0;
    for (int i = 0; i < NUM_SENSORS; i++) {
        if (calibrated[i] > 500) {
            binary |= (1 << i);
        }
    }
    return binary;
}

/* =========================================================================
 * 9. PID COMPUTATION FUNCTION
 * ========================================================================= */
void pid_reset(pid_t *pid)
{
    pid->integral            = 0.0f;
    pid->prev_error          = 0.0f;
    pid->filtered_derivative = 0.0f;
    pid->first_sample        = true;
}

float pid_compute(pid_t *pid, float error, float dt)
{
    pid->integral += error * dt;
    if (pid->integral > pid->integral_limit)  pid->integral = pid->integral_limit;
    if (pid->integral < -pid->integral_limit) pid->integral = -pid->integral_limit;

    float raw_derivative = 0.0f;
    if (!pid->first_sample && dt > 0.0f) {
        raw_derivative = (error - pid->prev_error) / dt;
    }
    pid->first_sample = false;
    pid->prev_error   = error;

    pid->filtered_derivative = (DERIVATIVE_FILTER_ALPHA * raw_derivative)
                             + ((1.0f - DERIVATIVE_FILTER_ALPHA) * pid->filtered_derivative);

    return (pid->kp * error) + (pid->ki * pid->integral) + (pid->kd * pid->filtered_derivative);
}

/* =========================================================================
 * 10. MOTOR DRIVER CONTROL FUNCTIONS
 * ========================================================================= */
void motor_gpio_init(void)
{
    uint64_t pin_mask = (1ULL << AIN1) | (1ULL << AIN2) |
                        (1ULL << BIN1) | (1ULL << BIN2) |
                        (1ULL << STBY);

    gpio_config_t io_conf = {
        .pin_bit_mask = pin_mask,
        .mode         = GPIO_MODE_OUTPUT,
        .pull_up_en   = GPIO_PULLUP_DISABLE,
        .pull_down_en = GPIO_PULLDOWN_DISABLE,
        .intr_type    = GPIO_INTR_DISABLE
    };
    gpio_config(&io_conf);

    gpio_set_level(STBY, 0);
    gpio_set_level(AIN1, 0);
    gpio_set_level(AIN2, 0);
    gpio_set_level(BIN1, 0);
    gpio_set_level(BIN2, 0);
}

void motor_pwm_init(void)
{
    ledc_timer_config_t ledc_timer = {
        .speed_mode      = LEDC_MODE,
        .duty_resolution = LEDC_DUTY_RES,
        .timer_num       = LEDC_TIMER,
        .freq_hz         = LEDC_FREQUENCY,
        .clk_cfg         = LEDC_AUTO_CLK
    };
    ledc_timer_config(&ledc_timer);

    ledc_channel_config_t chan_a = {
        .gpio_num   = PWMA_PIN,
        .speed_mode = LEDC_MODE,
        .channel    = CHANNEL_A,
        .timer_sel  = LEDC_TIMER,
        .duty       = 0,
        .hpoint     = 0
    };
    ledc_channel_config(&chan_a);

    ledc_channel_config_t chan_b = {
        .gpio_num   = PWMB_PIN,
        .speed_mode = LEDC_MODE,
        .channel    = CHANNEL_B,
        .timer_sel  = LEDC_TIMER,
        .duty       = 0,
        .hpoint     = 0
    };
    ledc_channel_config(&chan_b);
}

int clamp_duty(int duty)
{
    if (duty > MAX_DUTY) duty = MAX_DUTY;
    if (duty < 0) duty = 0;
    return duty;
}

void set_motor_speed(ledc_channel_t channel, int duty)
{
    duty = clamp_duty(duty);

    ledc_set_duty(LEDC_MODE, channel, duty);
    ledc_update_duty(LEDC_MODE, channel);
}

void drive(int left_speed, int right_speed)
{
    gpio_set_level(AIN1, 1);
    gpio_set_level(AIN2, 0);
    gpio_set_level(BIN1, 1);
    gpio_set_level(BIN2, 0);

    set_motor_speed(CHANNEL_A, left_speed);
    set_motor_speed(CHANNEL_B, right_speed);
}

/* =========================================================================
 * 11. SINGLE-BUTTON STATE MACHINE HANDLER
 * ========================================================================= */
void handle_single_button(void)
{
    if (btn_pressed) {
        btn_pressed = false;

        if (gpio_get_level(BTN_SINGLE_GPIO) == 0) {

            if (robot_state == ROBOT_STATE_IDLE) {
                robot_state = ROBOT_STATE_CALIBRATING;
                gpio_set_level(STBY, 0);

                for (int i = 0; i < NUM_SENSORS; i++) {
                    sensor_min[i] = 4095;
                    sensor_max[i] = 0;
                }
                ESP_LOGW(TAG, ">>> STATE: CALIBRATING (Sweep sensors across line) <<<");
            }
            else if (robot_state == ROBOT_STATE_CALIBRATING) {
                robot_state = ROBOT_STATE_IDLE;
                is_calibrated = true;
                ESP_LOGW(TAG, ">>> STATE: IDLE (Calibration Saved! Press again to RUN) <<<");
            }
            else if (robot_state == ROBOT_STATE_RUNNING) {
                robot_state = ROBOT_STATE_IDLE;
                junction_probing_active = false;
                gpio_set_level(STBY, 0);
                ESP_LOGW(TAG, ">>> STATE: IDLE (Robot Stopped) <<<");
            }
            else {
                robot_state = ROBOT_STATE_IDLE;
                gpio_set_level(STBY, 0);
            }
        }
    }
}

void handle_run_trigger_from_idle(void)
{
    if (btn_pressed && robot_state == ROBOT_STATE_IDLE && is_calibrated) {
        btn_pressed = false;
        if (gpio_get_level(BTN_SINGLE_GPIO) == 0) {
            robot_state = ROBOT_STATE_RUNNING;
            junction_probing_active = false;
            pid_reset(&line_pid);
            gpio_set_level(STBY, 1);
            ESP_LOGW(TAG, ">>> STATE: RUNNING STARTED <<<");
        }
    }
}

void app_main(void)
{
    sensors_init();
    buttons_init();
    leds_init();
    motor_gpio_init();
    motor_pwm_init();

    int raw[NUM_SENSORS];
    int calibrated[NUM_SENSORS];
    uint32_t log_counter = 0;

    ESP_LOGI(TAG, "System Ready! Press BTN (GPIO 4) to Start Calibration.");

    while (1) {
        if (robot_state == ROBOT_STATE_IDLE && is_calibrated) {
            handle_run_trigger_from_idle();
        } else {
            handle_single_button();
        }

        update_leds();
        read_sensors(raw);

        // --- STATE 1: CALIBRATING ---
        if (robot_state == ROBOT_STATE_CALIBRATING) {
            update_calibration(raw);
            vTaskDelay(pdMS_TO_TICKS(20));
            continue;
        }

        // --- STATE 2: RUNNING ---
        if (robot_state == ROBOT_STATE_RUNNING) {
            get_calibrated_values(raw, calibrated);
            float position = get_weighted_position(calibrated);
            uint8_t binary = get_sensors_binary(calibrated);

            int binary_count = 0;
            for (int i = 0; i < NUM_SENSORS; i++) {
                if (binary & (1 << i)) binary_count++;
            }

            int64_t now_us = esp_timer_get_time();

            /* -------------------------------------------------
             * TRIGGER CHECK FOR JUNCTION
             * ------------------------------------------------- */
            if (!junction_probing_active &&
                ((now_us - last_junction_time_us) > ((int64_t)JUNCTION_COOLDOWN_MS * 1000))) {

                if (is_left_junction_pattern(binary)) {
                    junction_probing_active = true;
                    junction_probe_start_us = now_us;
                    last_junction_time_us   = now_us;

                    ESP_LOGW(TAG, ">>> JUNCTION CANDIDATE DETECTED -> STARTING STRAIGHT PROBE <<<");
                }
            }

            /* -------------------------------------------------
             * MODE A: UNCONDITIONAL STRAIGHT DRIVE PROBE (PID OFF)
             * ------------------------------------------------- */
            if (junction_probing_active) {

                // Drive strictly straight past the junction stem
                drive(JUNCTION_STRAIGHT_SPEED, JUNCTION_STRAIGHT_SPEED);

                int64_t elapsed_ms = (now_us - junction_probe_start_us) / 1000;

                ESP_LOGI(TAG, "PROBE t=%lld ms | bin=%c%c%c%c%c%c%c%c | cnt=%d",
                         elapsed_ms,
                         (binary & (1 << 7)) ? '1' : '0',
                         (binary & (1 << 6)) ? '1' : '0',
                         (binary & (1 << 5)) ? '1' : '0',
                         (binary & (1 << 4)) ? '1' : '0',
                         (binary & (1 << 3)) ? '1' : '0',
                         (binary & (1 << 2)) ? '1' : '0',
                         (binary & (1 << 1)) ? '1' : '0',
                         (binary & (1 << 0)) ? '1' : '0',
                         binary_count);

                // Check if straight probe duration has completed
                if (elapsed_ms >= JUNCTION_STRAIGHT_DRIVE_MS) {

                    // Evaluate straight line using pattern matching + count + center mask
                    bool straight_line_present = check_straight_line_exists(binary, binary_count);

                    if (straight_line_present) {
                        ESP_LOGW(TAG, ">>> CLASSIFICATION: T-JUNCTION / CROSS (Straight Line Exists) <<<");
                    } else {
                        ESP_LOGW(TAG, ">>> CLASSIFICATION: L-JUNCTION (Dead End Straight -> Mandatory Left Turn) <<<");
                    }

                    // Reset probe state and re-enable PID line following
                    junction_probing_active = false;
                    pid_reset(&line_pid);
                    ESP_LOGI(TAG, ">>> PID ON - REJOINING LINE <<<");
                }
            }
            /* -------------------------------------------------
             * MODE B: NORMAL CLOSED-LOOP PID LINE FOLLOWING
             * ------------------------------------------------- */
            else {
                float correction = pid_compute(&line_pid, position, 0.02f);

                int left_speed  = BASE_SPEED - (int)correction;
                int right_speed = BASE_SPEED + (int)correction;

                drive(left_speed, right_speed);

                if (++log_counter >= 5) {
                    ESP_LOGI(TAG, "pos: %6.2f | corr: %6.2f | L:%4d R:%4d | bin: %c%c%c%c%c%c%c%c | cnt: %d",
                             position, correction, clamp_duty(left_speed), clamp_duty(right_speed),
                             (binary & (1 << 7)) ? '1' : '0',
                             (binary & (1 << 6)) ? '1' : '0',
                             (binary & (1 << 5)) ? '1' : '0',
                             (binary & (1 << 4)) ? '1' : '0',
                             (binary & (1 << 3)) ? '1' : '0',
                             (binary & (1 << 2)) ? '1' : '0',
                             (binary & (1 << 1)) ? '1' : '0',
                             (binary & (1 << 0)) ? '1' : '0',
                             binary_count);
                    log_counter = 0;
                }
            }
        } 
        else {
            gpio_set_level(STBY, 0);
        }

        vTaskDelay(pdMS_TO_TICKS(20));
    }
}

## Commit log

2026-08-13 Create sample file
2026-08-23 Created and added first CAD Files
    The part files like N20 MOTOR , WHEELS , MOUNTS are permanant and final , but files like Assembly and chasis refelect the current progress and will be edited in the future.
    Added both solidoworks and stl files of the parts
2026-08-23 Added CAD files
    [Assembly file.SLDASM, Line follower Chasis.SLDPRT, N20 Wheel D43 mm sld.SLDPRT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]
2026-08-23 Deleted sample file
2026-08-23 Added files like circuit architecture , BOM
2026-08-23 Create BOM.md
    Added BOM File , converted it into md format using ai initially it was in pdf format
2026-08-26 Update BUILDLOG.md
    added current progress for 26 august.
2026-08-26 New updated circuit architecture added
2026-08-29 Update BUILDLOG.md
    added the CAD Design near final work
2026-08-29 Update BUILDLOG.md
    added images of the CAD Files
2026-08-29 Update BUILDLOG.md
    3D Printing complete
2026-09-10 feat(firmware): add dual motor control logic with PWM
2026-09-19 this is the code used only for the sensor testing and calibration part which was done sepeartely from the motor code and now it would be fused with the motor code and will try a PID based run
2026-09-19 combuined my calibartion code and the motor code toogether and implmented a basic pid lop for it follow a line using the error from the position
    [main.c]
2026-09-24 implemented the deruivative filter and the anti intergral windup clamping
2026-09-28 pid+binary representation+motiors running done
2026-09-28 modified code for 1 button control rather than two button
